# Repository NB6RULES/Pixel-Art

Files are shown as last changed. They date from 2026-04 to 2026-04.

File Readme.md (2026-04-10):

# Pixel-Art

A CoreXY bead-placement machine for creating physical monochrome pixel art on perforated acrylic sheets.

## 3D Model Preview

[View 3D Model on Sketchfab](https://sketchfab.com/3d-models/pixel-art-first-draft-e8df2f01db034dc6a11d05934eb7d457)

## Overview

Pixel-Art is an open-source CNC machine that automatically places beads into a grid of holes on an acrylic sheet, producing physical pixel art from digital images. The machine uses a CoreXY motion system for fast, precise XY movement and a bead dropper mechanism as the end effector.

## Specifications

| Parameter | Value |
|---|---|
| Build Area | 400 × 400 mm |
| Resolution | 2–10 mm per pixel (configurable) |
| Color Mode | Monochrome (black, white, grey beads) |
| Motion System | CoreXY |
| Controller | ESP32 + GRBL |
| Frame | 2020 aluminum extrusion |
| Motors | NEMA17 steppers |
| Belt | GT2 timing belt |

## Roles 

MACHINE GANTERY -- NADEC
END EFFECTOR --- KEVIN
ELECTRONICS -- MERIN
FIRMWARE ---  ARCHITHA
INTERFACE --- KURIAN
DOCUMENTION --- MERIN
FABRICATION AND INTERGRATION --- KURIAN
PRESENTAION & VIDEO (1 MIN) --- ARCHITHA

## TIMELINE

APRIL 09 --  INITAL DISCUSSION AND TEAM ALLOCATION
APRIL 10 --  SKETCH THE DESIGN, MACHINE GANTERY DESIGN AND INTERFACE DESIGN (GET THE GCOD FOR MACHINE)
APRIL 11 --  DESIGN AND FIX THE END EFFECTOR WORKING STRUCTER 
APRIL 12 --  END EFFECTOR DESIGN ( GET THE PROPER MEASURMENT FOR THE BEADS AND BASED ON THAT WE NEEDED TO WORK, **DO IT PARAMETRIC** ), ELECTROCNIC DESIGN 
APRIL 13 --  CHECK THE GCODES WORKING GANTERY MOVEMENT, FIRMWARE 
APRIL 14 --
APRIL 15 -- FABRICATION AND INTERGRATION
APRIL 16 -- 
APRIL 17 --
APRIL 18 --
APRIL 19 --
APRIL (20 - 21) -- VIDEO EDITIONG &  PRESENTAION

## How It Works

1. **Image Input** — A monochrome image is converted to G-code with pixel coordinates mapped to hole positions
2. **Bead Loading** — Beads are loaded into the dropper mechanism (sorted by color)
3. **Placement** — The CoreXY gantry moves to each hole position and the dropper releases a bead
4. **Result** — Completed pixel art on the acrylic sheet

## Bill of Materials

### Frame & Motion

- 2020 V-slot aluminum extrusion
- GT2 timing belt + pulleys (16T/20T)
- NEMA17 stepper motors (×2 for XY)
- Linear rails / V-slot wheels
- 625 bearings for idlers

### Electronics

- ESP32 development board
- DRV8825 / TMC2209 stepper drivers
- 12V/24V power supply
- Limit switches (×3)

### End Effector

- Bead dropper mechanism (servo/solenoid actuated)
- Bead hopper/feeder

### Substrate

- Perforated acrylic sheet (hole spacing matches resolution)
- Beads (2–10 mm diameter, black/white/grey)

## Repository Structure

```
Pixel-Art/
├── Core-XY Movement - Nadec/
│   ├── Solidworks Files/      # Editable CAD files
│   ├── STL AND STEP FILES/    # Export files for fabrication
│   └── initial files/         # Reference designs
├── Documentation/
│   └── Documentation.md
└── README.md
```

## Build Status

- [x] CoreXY gantry design (first draft)
- [ ] End effector dropper mechanism
- [ ] Electronics integration
- [ ] Firmware (ESP32-GRBL)
- [ ] Image-to-Gcode converter
- [ ] Assembly documentation

---

## Git Workflow

### First Time Setup (Clone the Repo)

```bash
git clone https://github.com/NB6RULES/Pixel-Art.git
cd Pixel-Art
git lfs install
git lfs pull
```

> **Note:** This repo uses Git LFS for large STL/STEP files. Run `git lfs install` once on your machine.

### Daily Workflow

#### 1. Always Pull Before You Start Working

```bash
git pull
```

This syncs your local copy with the latest changes from GitHub.

#### 2. Check What's Changed

```bash
git status
```

Shows modified, staged, and untracked files.

#### 3. Stage Your Changes

```bash
# Add specific file
git add filename.SLDPRT

# Add all changes
git add .
```

#### 4. Commit Your Changes

```bash
git commit -m "Brief description of what you changed"
```

Write clear commit messages — future you will thank present you.

#### 5. Pull Again Before Pushing

```bash
git pull
```

**Always pull before push** to avoid merge conflicts, especially when collaborating.

#### 6. Push to GitHub

```bash
git push
```

### Quick Reference

| Command | What it does |
|---|---|
| `git clone <url>` | Download repo for the first time |
| `git pull` | Get latest changes from GitHub |
| `git status` | See what files changed |
| `git add .` | Stage all changes |
| `git commit -m "msg"` | Save changes locally with a message |
| `git push` | Upload commits to GitHub |
| `git log --oneline` | View commit history |

### Golden Rule

```
PULL → WORK → ADD → COMMIT → PULL → PUSH
```

---

## Getting Started

### Prerequisites

- SolidWorks (or use STEP files for other CAD software)
- 3D printer for custom brackets
- Basic CNC/electronics assembly experience

### Assembly

*Documentation in progress*

## Dependencies & Key Libraries

### [GRBL](https://github.com/grbl/grbl)
The original open-source, high-performance G-code motion controller written in optimized C. GRBL is the foundation of the motion control strategy used in this project — it handles real-time step generation, acceleration planning, and G-code parsing. We reference it as the upstream standard that our ESP32 port is based on.

### [Grbl_ESP32 (bdring)](https://github.com/bdring/grbl_esp32)
A port of GRBL adapted specifically for the ESP32 microcontroller. We chose this because the ESP32 offers Wi-Fi connectivity, more GPIO pins, and faster processing than the original Arduino Uno target. This firmware runs directly on our controller board and interprets G-code sent from the image processing pipeline.

### [NeoPI_Wireless (saheenpalayi)](https://github.com/saheenpalayi/NeoPI_Wireless)
A wireless interface layer for sending G-code over Wi-Fi to an ESP32-based CNC controller. We use this (or draw from its approach) to enable cable-free communication between the host computer and the machine — the image-to-G-code output is streamed wirelessly to the ESP32 rather than requiring a USB connection.

---

## Firmware

This project uses [Grbl_Esp32](https://github.com/bdring/Grbl_Esp32) for motion control. Configuration files and pin mappings will be added once electronics design is finalized.

## Software Pipeline

```
Image → Dithering/Thresholding → Grid Mapping → G-code → ESP32-GRBL → Machine
```

A Python script for image processing and G-code generation is planned.

---

## License

*TBD*

---

## Authors

**Nadec Biju**   - COREXY
- GitHub: [@NB6RULES](https://github.com/NB6RULES)

**Architha B K**  
- GitHub: [@architabk618-hue](https://github.com/architabk618-hue)

**Kurian**   - INTERFACE 
- GitHub: [@Kuriyaappi](https://github.com/Kuriyaappi)

**Kevin J Jijo**  - END E
- GitHub: [@mrkubby](https://github.com/mrkubby)

**Merin Menamparambil**  
- GitHub: [@merinmenamparambil](https://github.com/merinmenamparambil)

## CoreXY References

### [CoreXY.com](https://corexy.com/)
The original reference site documenting the CoreXY motion system concept, belt routing geometry, and kinematics. Used as the primary reference for understanding how the two-motor H-bot style drive works and how to correctly route belts to achieve true CoreXY motion without shear forces.

### [Jubilee (Machine Agency)](https://github.com/machineagency/jubilee)
An open-source CoreXY toolchanging machine designed for research and fabrication. Referenced for its well-engineered CoreXY gantry design, use of 2020 extrusion framing, and modular tool head approach — directly relevant to how we've structured our own gantry and end effector mounting.

---

## Acknowledgments

- Inspired by bead art and CNC plotters
- McMaster-Carr for hardware CAD models

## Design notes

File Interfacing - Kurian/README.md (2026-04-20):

# Pixel Bead Placer — CoreXY

A browser-based pixel art editor that streams G-code over USB serial to a CoreXY machine running grbl_esp32, which physically places beads on a configurable bed one at a time.

---

## Table of Contents

1. [Project Purpose](#1-project-purpose)
2. [System Architecture](#2-system-architecture)
3. [Interface Layout](#3-interface-layout)
4. [Left Sidebar — Settings & Tools](#4-left-sidebar--settings--tools)
5. [Canvas Area — Preview](#5-canvas-area--preview)
6. [Right Panel — Machine Control](#6-right-panel--machine-control)
7. [Pre-run Checklist Flow](#7-pre-run-checklist-flow)
8. [USB Serial Communication Protocol](#8-usb-serial-communication-protocol)
9. [GRBL Command Reference](#9-grbl-command-reference)
10. [G-code Program Structure](#10-g-code-program-structure)
11. [Bead Feeder Control](#11-bead-feeder-control)
12. [Coordinate System](#12-coordinate-system)
13. [Grid & Spacing Model](#13-grid--spacing-model)
14. [Image Import](#14-image-import)
15. [SVG Export](#15-svg-export)
16. [Firmware Requirements (ESP32 / grbl_esp32)](#16-firmware-requirements-esp32--grbl_esp32)
17. [Hardware Summary](#17-hardware-summary)
18. [File Structure](#18-file-structure)
19. [Settings Reference](#19-settings-reference)
20. [Changelog](#20-changelog)

---

## 1. Project Purpose

The operator designs a black-and-white pixel image in a browser. The browser app converts it to a grid of bead positions, then streams G-code commands one-by-one over USB serial to a CoreXY robot. The robot moves its end-effector to each position and drops a bead (black or white) using motorised feeders, assembling the physical pixel art on a flat tray.

---

## 2. System Architecture

```
┌─────────────────────────────────────────────────────────┐
│                   Browser (Chrome / Edge)                │
│                                                         │
│  Left sidebar   │   Canvas preview   │  Machine panel   │
│  (settings)     │   (grid, rulers)   │  (serial ctrl)   │
│                                                         │
│         Web Serial API (USB CDC, 115200 baud)           │
└──────────────────────────┬──────────────────────────────┘
                           │ USB
                           ▼
              ┌────────────────────────┐
              │   ESP32 dev board      │
              │   grbl_esp32 firmware  │
              │   (GRBL 1.1 protocol)  │
              └────────────┬───────────┘
                           │ Step/Dir signals
                           ▼
              ┌────────────────────────┐
              │   CoreXY motion system │
              │   + 2 bead feeders     │
              │   + limit switches     │
              └────────────────────────┘
```

**Communication path:** Browser → Web Serial API → USB CDC → ESP32 UART0 → grbl_esp32

**Data format:** Plain ASCII text, newline-terminated (`\n`). No binary framing, no checksum.

---

## 3. Interface Layout

The app is a single-page HTML application with three columns inside a full-viewport layout:

```
┌──────────────────────────────────────────────────────────────────────┐
│  HEADER: title + "Generate & Download GCode" button                   │
├──────────────┬───────────────────────────────┬───────────────────────┤
│  LEFT PANEL  │        CANVAS AREA            │    RIGHT PANEL        │
│  224 px      │        flex: 1 (scrollable)   │    262 px             │
│              │                               │                       │
│  • Bed/Bead  │  Y ruler │ Grid preview       │  • Serial connect     │
│    Setup     │  (left)  │ (bead circles)     │  • Pre-run checklist  │
│              │          │                    │  • Machine state      │
│  • Bead      │          │ X ruler (bottom)   │  • Jog controls       │
│    Count     │                               │  • Print job          │
│              │                               │  • Terminal           │
│  • Colors    │                               │                       │
│              │                               │                       │
│  • Tools     │                               │                       │
│              │                               │                       │
│  • Machine   │                               │                       │
│    Settings  │                               │                       │
│              │                               │                       │
│  • Actions   │                               │                       │
└──────────────┴───────────────────────────────┴───────────────────────┘
```

---

## 4. Left Sidebar — Settings & Tools

### 4.1 Bed & Bead Setup

Inputs that define the physical machine and the design grid. All are numbers in mm.

| Field | HTML ID | Default | Description |
|---|---|---|---|
| Bed width | `#bed-w` | 400 | Machine bed width in mm |
| Bed height | `#bed-h` | 400 | Machine bed height in mm |
| Bead size | `#bead-diameter` | 6 | Physical bead diameter in mm |
| Gap | `#bead-gap` | 1 | Edge-to-edge clearance between beads in mm |
| Spacing (read-only) | `#spacing-val` | 7 | Auto-computed: diameter + gap |

Click **Apply Grid** to commit these values. The canvas will render and all design tools unlock. If a design already exists and values change, the user is asked to confirm clearing it.

### 4.2 Bead Count (shown after Apply Grid)

Live stats displayed in `#grid-info`:
- Grid: cols × rows
- Total beads
- Black bead count
- White bead count

A warning banner appears if total > 40,000 beads (large G-code file).

### 4.3 Colors

Three `<input type="color">` pickers, all live (no Apply needed):

| Picker | HTML ID | Default | Controls |
|---|---|---|---|
| Black bead | `#color-black` | `#1a1a1a` | Fill color of black bead circles on canvas |
| White bead | `#color-white` | `#f0f0f0` | Fill color of white bead circles on canvas |
| Space | `#color-space` | `#999999` | Background between beads |

### 4.4 Tools (locked until Apply Grid)

- **Pen** (`data-tool="pen"`) — click/drag to place black beads
- **Eraser** (`data-tool="eraser"`) — click/drag to place white beads (remove black)
- **Show Path** (`#btn-path`) — toggles the snake path overlay on the canvas

### 4.5 Machine Settings

These values feed directly into G-code generation and the machine panel:

| Field | HTML ID | Default | Description |
|---|---|---|---|
| Origin X | `#origin-x` | 0 | X offset added to all G-code positions |
| Origin Y | `#origin-y` | 0 | Y offset added to all G-code positions |
| Move speed | `#move-speed` | 800 | Feed rate for positioning moves in mm/min |
| Dwell time | `#dwell-time` | 300 | `G4 P` value in ms; wait after each bead drop |
| Black bead | `#black-bead-side` | Left | Which side of the dropper dispenses black beads |
| White bead | `#white-bead-side` | Right | Which side of the dropper dispenses white beads |

### 4.6 Actions (locked until Apply Grid)

- **Import Image** (`#btn-import`) — opens a file picker; image is luminance-thresholded to black/white and mapped to the grid
- **Download SVG** (`#btn-svg`) — saves a physically accurate SVG of the current design
- **Clear All** (`#btn-clear`) — resets all beads to white (after user confirm)

The header button **Generate & Download GCode** (`#btn-gcode`) saves the current design as a `.gcode` file.

---

## 5. Canvas Area — Preview

### 5.1 Coordinate System

The canvas uses a **Y-up coordinate system** matching standard machine/CAD conventions:

- **(0, 0) is at the bottom-left** corner of the bed
- **X increases to the right**
- **Y increases upward**
- Row 0 in the grid array = bottom-most row on screen = smallest Y in G-code
- Row N-1 in the grid array = top-most row on screen = largest Y in G-code

### 5.2 Canvas Layout

```
Canvas pixel layout:

 y=0 ──────────────────────────────────────
      │  Y ruler  │     Grid area          │
      │  (44 px)  │  (cols × cellPx wide)  │
      │           │                        │
      │  Y=max    │  row N-1 (top)         │
      │  at top   │                        │
      │  Y=0      │  row 0 (bottom)        │
      │  at btm   │                        │
 y=rows*cellPx ──┼────────────────────────┤
      │  corner   │     X ruler            │
      │  "mm"     │  (canvas width wide)   │
 y=canvas.height ─────────────────────────
      │← RULER_PX→│←── cols × cellPx ─────│
```

- `RULER_PX = 44` px — width of Y ruler strip (also height of X ruler strip)
- `cellPx = clamp(floor(680 / cols), 5, 40)` — pixels per bead cell

### 5.3 Rulers

- **Y ruler** (left, 44 px wide): tick marks at every `rulerLabelStep()` rows; labels show Y in mm; small ▶/◀ arrows show snake-path travel direction per row
- **X ruler** (bottom, 44 px tall): tick marks at every `rulerLabelStep()` cols; labels show X in mm
- **Corner square** at bottom-left: labelled "mm"
- Tick density adapts to zoom level — minimum 45 px between major tick labels

### 5.4 Grid Rendering

Each bead is a filled circle:

```
radiusPx = (beadDiameterMm / beadSpacingMm) × cellPx × 0.5
```

Bead at grid position (col, row):
```
canvas_x = RULER_PX + col × cellPx + cellPx / 2
canvas_y = (rows - 1 - row) × cellPx + cellPx / 2
```

Background (space between beads) = `colorSpace`; black bead = `colorBlack`; white bead = `colorWhite`.

### 5.5 Snake Path Overlay

When **Show Path** is active, a semi-transparent red line traces the full travel sequence:
- Even rows (0, 2, 4…): left → right
- Odd rows (1, 3, 5…): right → left
- Arrowheads at the start of every labelled row

---

## 6. Right Panel — Machine Control

All machine interaction is in the right panel (262 px wide). It is always visible regardless of grid state.

### 6.1 Serial Connection

- **Connect USB** button (`#btn-serial-connect`) — calls `navigator.serial.requestPort()` and opens at 115200 baud
- Status indicator: green dot = connected, dark dot = disconnected
- On connect: all machine buttons enable; status is polled after 1.2 s
- On disconnect: all buttons disable; running job is aborted; cmdQueue is flushed

### 6.2 Pre-run Checklist

Seven items. Each has a state: `pending` (○), `busy` (…), `done` (✓). Items 2–6 have action buttons that become enabled once connected.

| # | ID | Label | Action | How it completes |
|---|---|---|---|---|
| 1 | `#chk-connect` | Connect to machine | (automatic) | Ticks on USB connect |
| 2 | `#chk-home` | Home axes (limit switches) | Run $H | Sends `$H`, waits for `ok` |
| 3 | `#chk-origin` | Move to origin X/Y | Go | Sends `G21 G90 G0 X{ox} Y{oy}`, waits for `ok` |
| 4 | `#chk-testx` | Test X axis movement | Test | Jogs X+ then X−, user confirms |
| 5 | `#chk-testy` | Test Y axis movement | Test | Jogs Y+ then Y−, user confirms |
| 6 | `#chk-testbead` | Test bead drop | Test | Moves to slot 1 → drops black bead → moves to slot 2 → drops white bead; user confirms each |
| 7 | `#chk-ready` | Ready to print | (automatic) | Ticks when items 1–6 all done |

When **Run** is clicked and the checklist is not fully complete, the user is shown a warning and can proceed anyway.

### 6.3 Machine State

Polled by sending `?` to GRBL. The response (`<...>` status report) is parsed silently (not shown in terminal) and updates:

| Display | ID | Source |
|---|---|---|
| Status | `#mc-status` | First field of status report (e.g. `Idle`, `Run`, `Alarm`) |
| X position | `#mc-pos-x` | `WPos:x,...` parsed from status report |
| Y position | `#mc-pos-y` | `WPos:x,y,...` parsed from status report |

The `?` button (`#btn-poll`) manually triggers a poll.

### 6.4 Jog Controls

3×3 directional pad. All jog commands use GRBL jogging (`$J=`) in relative mode:

```
$J=G91 G21 X{±step} F{feed}
$J=G91 G21 Y{±step} F{feed}
```

- **Step size** (`#jog-step`): 1 / 5 / 10 / 50 mm
- **Feed rate** (`#jog-feed`): slow=1000, med=3000, fast=6000 mm/min
- **⌂ button** (`#jog-center`): sends `G0 X{originX} Y{originY} F3000` — returns to user-defined origin
- All jog buttons disabled during a running or paused job

### 6.5 Print Job

- **▶ Run** (`#btn-run-gcode`) — builds G-code from current grid state via `buildGcodeLines()`, then streams lines one-by-one
- **⏸ Pause** — sets `jobPaused = true`; current line finishes; no new lines sent; button changes to **▶ Resume**
- **■ Stop** — sets job state to stopped; sends `!` (feed hold) then `\x18` (soft reset) 250 ms later
- Progress bar and `Line N / total (N%)` counter update after each line sent
- Run button enabled when: serial connected AND grid is ready (`gridReady = true`)

### 6.6 Terminal

- Colour-coded log of all serial traffic:
  - `← ` green — data received from machine (RX)
  - `→ ` blue — data sent to machine (TX)
  - `# ` grey — system messages from the browser app
  - `✗ ` red — errors
- GRBL status reports (`<...>`) are parsed silently and do **not** appear in the terminal (to avoid flooding during a job)
- Manual command input (`#serial-cmd`) — type any GRBL command and press Enter or Send
- **Clear** button wipes the terminal log
- Capped at 600 lines (oldest lines removed automatically)

---

## 7. Pre-run Checklist Flow

The expected sequence before every print run:

```
Step 1: Connect USB
  → User clicks "Connect USB"
  → Browser opens port picker dialog
  → Port opens at 115200 baud
  → App waits 1.2 s, sends ?
  → chk-connect ticks ✓

Step 2: Home axes
  → User clicks "Run $H"
  → App sends:  $H\n
  → GRBL runs homing cycle (moves to limit switches)
  → GRBL replies: ok
  → chk-home ticks ✓
  → App sends ? to refresh position display
  (If ALARM state, user must send $X in terminal first)

Step 3: Move to origin
  → User clicks "Go"
  → App sends:  G21\n   (mm mode)
                G90\n   (absolute)
                G0 X{originX} Y{originY} F3000\n
  → GRBL replies: ok, ok, ok
  → chk-origin ticks ✓
  → App sends ? to refresh position display

Step 4: Test X axis
  → User clicks "Test"
  → App sends:  $J=G91 G21 X{step} F{feed}\n
  → GRBL replies: ok
  → App sends:  $J=G91 G21 X{-step} F{feed}\n
  → GRBL replies: ok
  → Browser shows confirm dialog: "Did the machine move correctly in X?"
  → User clicks OK → chk-testx ticks ✓
  → User clicks Cancel → item stays pending, can retry

Step 5: Test Y axis
  → Same as step 4 but Y direction

Step 6: Test bead drop
  → User clicks "Test"
  → App sends:  G1 X{slot1X} Y{slot1Y} F{speed}\n   (move to first bead slot)
  → GRBL replies: ok
  → App sends:  G4 P0\n                               (full stop)
  → App sends:  M3 S{BLACK}\n                         (drop black bead)
  → App sends:  G4 P{dwellMs}\n                       (dwell)
  → App sends:  M3 S60\n                              (rest)
  → Browser shows confirm: "Did a BLACK bead drop?" → OK to continue
  → App sends:  G1 X{slot2X} Y{slot2Y} F{speed}\n   (move to next slot)
  → Same sequence for white bead
  → Both confirmed → chk-testbead ticks ✓

Step 7: Ready to print
  → Auto-ticks when all 6 above are ✓

Step 8: Run
  → User clicks ▶ Run
  → App builds G-code from current grid
  → Streams line-by-line (see §8.3)
```

---

## 8. USB Serial Communication Protocol

### 8.1 Physical Layer

| Parameter | Value |
|---|---|
| Interface | USB CDC (virtual COM port) |
| Baud rate | 115200 |
| Data bits | 8 |
| Stop bits | 1 |
| Parity | None |
| Flow control | None (software flow control via GRBL `ok` responses) |
| Browser API | Web Serial API (Chrome ≥ 89, Edge ≥ 89) |

### 8.2 Message Format

All messages are plain ASCII terminated by `\n` (LF, `0x0A`). GRBL may send `\r\n` — the app strips `\r` before processing.

**Browser → Machine (TX):**  each command is a single line followed by `\n`

**Machine → Browser (RX):**  GRBL sends one response per command received

### 8.3 Flow Control — ok Gating

The app uses strict single-command flow control:

```
Browser sends line 1 ──→ Machine
                     ←── ok
Browser sends line 2 ──→ Machine
                     ←── ok
...
```

Only one line is in flight at any time. The next line is sent only after `ok` is received for the previous one. This prevents GRBL's 128-byte RX buffer from overflowing.

**Implementation:**
- `sendCmd(cmd)` — returns a Promise that resolves on `ok`, rejects on `error:N` or `ALARM:N`
- `sendRaw(cmd)` — fire-and-forget (used for `?`, `!`, `\x18` which don't follow the ok protocol)
- During a job, incoming `ok` triggers `sendNextJobLine()`
- During interactive use (checklist, jog, terminal), `ok` resolves the top entry in `cmdQueue[]`

### 8.4 Response Types

| Response | When sent | App behaviour |
|---|---|---|
| `ok` | After any valid command executes | Advances job queue or resolves cmdQueue promise |
| `error:N` | Invalid command or parameter | Logs to terminal; pauses job if running |
| `ALARM:N` | Machine alarm (limit hit, homing fail, etc.) | Logs to terminal; stops job; cmdQueue rejected |
| `<State\|WPos:x,y,z\|...>` | Response to `?` status request | Parsed silently; updates status display |
| `[MSG:...]` | Informational messages (e.g. homing) | Shown in terminal |
| `Grbl N.N ...` | Welcome message on connect/reset | Shown in terminal |
| `$` settings replies | Response to `$$` | Shown in terminal |

### 8.5 Special Real-time Commands

These are single-byte commands sent without `\n`. They are processed by GRBL immediately, bypassing the command buffer:

| Byte | Command | Effect |
|---|---|---|
| `?` | Status request | GRBL sends `<State\|WPos:x,y,z\|...>` immediately |
| `!` | Feed hold | Machine decelerates to stop; state → `Hold` |
| `~` | Cycle start / resume | Resumes from Hold |
| `\x18` (Ctrl-X) | Soft reset | Resets GRBL; clears alarms; machine state lost |

The Stop button sends `!` then `\x18` after 250 ms.

### 8.6 Status Report Format

GRBL sends a status report in response to `?`:

```
<Idle|WPos:10.500,25.000,0.000|FS:0,0>
<Run|WPos:10.500,25.000,0.000|FS:3000,0>
<Alarm:9|WPos:0.000,0.000,0.000|FS:0,0>
<Hold:0|WPos:10.500,25.000,0.000|FS:0,0>
```

Fields:
- **State**: `Idle`, `Run`, `Hold:0`, `Hold:1`, `Jog`, `Alarm:N`, `Door:N`, `Check`, `Home`, `Sleep`
- **WPos**: Work position X, Y, Z in mm (after applying work coordinate offset)
- **FS**: Feed rate (mm/min), Spindle speed (RPM)

The app parses `WPos` with:
```
/WPos:([-\d.]+),([-\d.]+)/
```

### 8.7 Homing Response Sequence

After `$H` is sent, GRBL typically responds:

```
[MSG:Caution: Unlocked]      ← if previously in ALARM
ok                            ← homing complete; machine now at (0,0,0)
```

Or on failure:
```
ALARM:9                       ← homing failed (limit switch not triggered)
```

If machine is in ALARM before homing, send `$X` first to unlock, then `$H`.

### 8.8 Jog Command Format

```
$J=G91 G21 X10 F3000\n
```

- `$J=` — jog prefix (GRBL 1.1+)
- `G91` — relative positioning for this move
- `G21` — mm units
- `X10` or `Y-5` — axis and distance
- `F3000` — feed rate in mm/min

GRBL responds with `ok` when the jog completes or is cancelled. Sending another `$J` while jogging cancels the current jog and starts the new one.

---

## 9. GRBL Command Reference

All commands used by this application:

| Command | Description | Expected Response |
|---|---|---|
| `?` | Request status report | `<State\|WPos:...>` (no `ok`) |
| `$H` | Run homing cycle | `ok` (after homing completes) |
| `$X` | Clear ALARM state (unlock) | `ok` |
| `$J=G91 G21 X{n} F{f}` | Jog X relative | `ok` |
| `$J=G91 G21 Y{n} F{f}` | Jog Y relative | `ok` |
| `G21` | Set units to mm | `ok` |
| `G90` | Absolute positioning mode | `ok` |
| `G28` | Go to pre-defined home position | `ok` |
| `G1 X{x} Y{y} F{f}` | Controlled linear move to position | `ok` |
| `G4 P0` | Flush planner — ensure machine fully stopped | `ok` |
| `G4 P{ms}` | Dwell for N milliseconds | `ok` (after dwell) |
| `M3 S110` | Servo → Left bead | `ok` |
| `M3 S22` | Servo → Right bead | `ok` |
| `M3 S60` | Servo → Rest (neutral) | `ok` |
| `M30` | End of program | `ok` |
| `!` | Feed hold (real-time, no `\n`) | (machine decelerates) |
| `\x18` | Soft reset (real-time, no `\n`) | `Grbl N.N ...` welcome |

---

## 10. G-code Program Structure

The full G-code program generated by `buildGcodeLines()`:

```gcode
; Pixel Bead Placer — GCode
; Firmware      : grbl_esp32 (GRBL 1.1 compatible)
; Bed size      : 400 x 400 mm
; Bead diameter : 6 mm
; Bead gap      : 1 mm  (edge-to-edge clearance)
; Bead spacing  : 7 mm  (center-to-center = diameter + gap)
; Grid          : 57 x 57  (3,249 beads)
; Black beads   : 1420
; White beads   : 1829
; Origin        : X0 Y0 mm
; Dwell/bead    : 300 ms
; Generated     : 2024-01-15T10:23:00.000Z
;
; Servo control (GPIO 27, 50Hz PWM):
;   M3 S110  →  Left  bead
;   M3 S22   →  Right bead
;   M3 S60   →  Rest (neutral)
;   BLACK bead = left side (M3 S110)
;   WHITE bead = right side (M3 S22)

G21            ← mm units
G90            ← absolute positioning
M3 S60         ← servo to rest before homing
G28            ← home all axes (machine goes to 0,0,0)

; Row 0  (L→R)
G1 X3.50 Y3.50 F800    ← controlled move to slot
G4 P0                  ← full stop before drop
M3 S110                ← drop black bead (left side)
G4 P0.300              ← dwell 300 ms
M3 S60                 ← servo back to rest

G1 X10.50 Y3.50 F800
G4 P0
M3 S22                 ← drop white bead (right side)
G4 P0.300
M3 S60
...

; Row 1  (R→L)
...

G28          ← return to home
M30          ← end of program
```

**Streaming rule:** Comment lines (starting with `;`) and blank lines are skipped when streaming. Only executable lines are sent to the machine. Each executable line waits for `ok` before the next is sent.

---

## 11. Bead Dropper Control

A single servo on GPIO 27 dispenses beads by rotating left or right from a neutral rest position. All control is via `M3 S{value}` — no M4 or M5 used.

### Calibrated S values

| Command | Action |
|---|---|
| `M3 S110` | Servo → Left position |
| `M3 S22` | Servo → Right position |
| `M3 S60` | Servo → Rest (neutral) |

### Bead side assignment

The user configures which physical side holds each bead colour in the Machine Settings panel. The generated S values adjust accordingly:

| User setting | Black bead command | White bead command |
|---|---|---|
| Black=Left, White=Right | `M3 S110` | `M3 S22` |
| Black=Right, White=Left | `M3 S22` | `M3 S110` |

### Per-bead drop sequence

Every bead — regardless of colour — follows this exact sequence:

```
G1 X{x} Y{y} F{speed}   ← controlled move to bead slot
G4 P0                    ← flush planner; full stop
M3 S{BLACK or WHITE}     ← rotate servo to drop bead
G4 P{dwell}              ← wait for bead to fall
M3 S60                   ← return servo to rest
```

`G4 P0` before the servo command guarantees the machine has fully decelerated and stopped before any bead is released, preventing mis-drops at speed.

**Startup:** `M3 S60` is sent before `G28` so the servo is always in the rest position before homing begins.

**Dwell (`G4 P{ms}`):** Default 300 ms, configurable 10–9999 ms.

**Move speed:** Default 800 mm/min (`G1 F800`), configurable 100–5000 mm/min.

---

## 12. Coordinate System

### 12.1 Machine Coordinates

- Machine home (after `$H`): X=0, Y=0
- X increases in one direction across the bed
- Y increases in the other direction across the bed (perpendicular to X in a CoreXY frame, but motion is coupled)
- Z is not used (the end-effector height is fixed)

### 12.2 G-code Bead Coordinates

For bead at grid position (col, row):

```
X_mm = originX + col × beadSpacingMm + beadSpacingMm / 2
Y_mm = originY + row × beadSpacingMm + beadSpacingMm / 2
```

- `originX`, `originY` — user-defined offset from machine home (default 0, 0)
- `beadSpacingMm` = bead diameter + gap
- `+ beadSpacingMm / 2` — centres the end-effector on the bead position

Row 0 = lowest Y value = front of bed = starts bottom-left in preview.

### 12.3 Snake Path

```
Row 0:  col 0 → col 1 → ... → col N-1    (left to right,  even rows)
Row 1:  col N-1 → ... → col 1 → col 0   (right to left,  odd rows)
Row 2:  col 0 → col 1 → ... → col N-1   (left to right,  even rows)
...
```

This minimises total travel distance by avoiding retracing the X axis at the end of each row.

### 12.4 Preview vs Machine Coordinates

The canvas preview matches the machine coordinate system exactly:
- (0,0) = bottom-left of canvas grid = machine origin (0+offset, 0+offset)
- Y increases upward in the preview (flipped from screen Y)
- X ruler at bottom, Y ruler at left

---

## 13. Grid & Spacing Model

```
beadSpacingMm = beadDiameterMm + beadGapMm

cols = floor(bedWidthMm  / beadSpacingMm)
rows = floor(bedHeightMm / beadSpacingMm)
```

Example: 400×400 mm bed, 6 mm bead, 1 mm gap:
- spacing = 7 mm
- cols = floor(400/7) = 57
- rows = floor(400/7) = 57
- total = 3,249 beads

The gap is edge-to-edge clearance — the physical space between adjacent bead edges. Center-to-center pitch equals diameter + gap.

Canvas cell size: `cellPx = clamp(floor(680 / cols), 5, 40)`

Circle radius on canvas: `radiusPx = (beadDiameterMm / beadSpacingMm) × cellPx × 0.5`

---

## 14. Image Import

1. User selects any image file (JPEG, PNG, GIF, WebP, etc.)
2. Image is drawn to an offscreen canvas scaled to `cols × rows`
3. Each pixel's luminance is computed:
   ```
   luma = 0.299 × R + 0.587 × G + 0.114 × B
   ```
4. `luma < 128` → black bead (`grid[r][c] = 1`)
5. `luma ≥ 128` → white bead (`grid[r][c] = 0`)
6. The result replaces the current design; stats and canvas update immediately

The offscreen canvas uses `fillStyle = '#ffffff'` before drawing to ensure transparent pixels map to white.

---

## 15. SVG Export — Laser Cut Template

The **Download SVG** button generates a laser-cutting template for the physical base plate.

### Purpose

The SVG is used to laser-cut the bead holder plate — a flat sheet with a hole at every bead position. The operator places this plate on the machine bed; the CoreXY end-effector drops beads through the holes into the tray below.

### Format

- **No fills** — outlines only (`fill="none"`)
- **Stroke colour: red** (`stroke="red"`) — standard colour used by laser cutter software to identify cut paths
- **Stroke width: 0.1 mm** (`stroke-width="0.1"`) — hairline cut line
- **Bed border** — one rectangle at the outer edge of the plate
- **Bead holes** — one circle per bead position, all identical regardless of black/white color in the design
- **File name:** `bead_plate_lasercut.svg`

### Example output

```xml
<svg xmlns="http://www.w3.org/2000/svg"
     width="400mm" height="400mm"
     viewBox="0 0 400 400">
  <g fill="none" stroke="red" stroke-width="0.1">
    <rect x="0" y="0" width="400" height="400"/>  <!-- bed border -->
    <circle cx="3.500" cy="3.500" r="3"/>          <!-- bead hole -->
    <circle cx="10.500" cy="3.500" r="3"/>
    ...
  </g>
</svg>
```

### Geometry

- `cx = col × beadSpacingMm + beadSpacingMm / 2`
- `cy = row × beadSpacingMm + beadSpacingMm / 2`
- `r  = beadDiameterMm / 2`
- All values in mm; SVG `width`/`height` set in mm so scale is 1:1 physical

Note: SVG Y-axis is top-down (row 0 at top). This does not affect the laser cut result since the plate is physically symmetric.

---

## 16. Firmware Requirements (ESP32 / grbl_esp32)

Any firmware flashed to the ESP32 must satisfy these requirements for the browser app to work correctly.

### 16.1 Protocol

- **GRBL 1.1 compatible** — the app assumes standard GRBL 1.1 command and response format
- **USB CDC serial** at **115200 baud**, 8N1
- Send a welcome string on boot: `Grbl N.N ['$' for help]` — this lets the app detect connection
- Respond `ok` (lowercase, alone on a line) after every successfully received and queued command
- Respond `error:N` for invalid commands (N = GRBL error code)
- Respond `ALARM:N` for alarm conditions

### 16.2 Commands the Firmware Must Handle

| Command | Required behaviour |
|---|---|
| `?` | Immediately respond with `<State\|WPos:x,y,z\|FS:feed,spindle>` without consuming an `ok` slot |
| `$H` | Run homing cycle using limit switches; respond `ok` when complete |
| `$X` | Clear alarm state; respond `ok` |
| `G21` | Set internal units to mm; respond `ok` |
| `G90` | Set absolute positioning mode; respond `ok` |
| `G28` | Move to stored home position (or machine zero); respond `ok` |
| `G0 X{x} Y{y} F{f}` | Rapid linear move to absolute position; respond `ok` when move completes |
| `G4 P{ms}` | Dwell for specified milliseconds; respond `ok` after dwell |
| `M3 S110` | Servo to left position; respond `ok` |
| `M3 S22` | Servo to right position; respond `ok` |
| `M3 S60` | Servo to rest (neutral); respond `ok` |
| `M30` | End of program; respond `ok` |
| `$J=G91 G21 X{n} F{f}` | Execute relative jog move; respond `ok` |
| `!` | Feed hold (real-time byte, no `ok` sent) |
| `\x18` | Soft reset (real-time byte; re-send welcome string) |

### 16.3 Spindle → Servo Mapping

The ESP32 firmware maps GRBL spindle S-values to PWM pulse widths on GPIO 27 (50 Hz BESC output):

```
M3 S110  →  Left  position  (drops left bead)
M3 S22   →  Right position  (drops right bead)
M3 S60   →  Rest  position  (neutral — no bead dropped)
```

Firmware type: `SPINDLE_TYPE = BESC`, output pin: `GPIO_NUM_27`. The S-value maps linearly to pulse width within the configured min/max range.

### 16.4 Homing

- Limit switches must be connected to the ESP32 inputs configured in grbl_esp32 settings
- `$H` triggers the homing cycle: machine moves toward limit switches at homing speed, backs off, and sets machine position to (0, 0, 0)
- After homing, `WPos` in status reports should read `0.000, 0.000, 0.000`
- Homing direction and speed are configured via GRBL `$` settings (e.g. `$23`, `$24`, `$25`)

### 16.5 Position Reporting

The `?` status response must include work position (`WPos`):
```
<Idle|WPos:10.500,25.000,0.000|FS:3000,100>
```

The app parses only X and Y from `WPos`. Z is ignored. `MPos` (machine position) can also be used if WPos is not available — update the regex in `parseGrblStatus()` accordingly.

### 16.6 GRBL Settings (recommended starting values)

Configure via `$$` command in the GRBL terminal:

| Setting | Parameter | Recommended |
|---|---|---|
| `$0` | Step pulse time (µs) | 10 |
| `$1` | Step idle delay (ms) | 25 |
| `$2` | Step port invert mask | depends on wiring |
| `$3` | Direction port invert | depends on wiring |
| `$4` | Step enable invert | 0 |
| `$20` | Soft limits enable | 1 |
| `$21` | Hard limits enable | 1 |
| `$22` | Homing cycle enable | 1 |
| `$23` | Homing direction invert | depends on wiring |
| `$24` | Homing feed rate (mm/min) | 25 |
| `$25` | Homing seek rate (mm/min) | 500 |
| `$27` | Homing pull-off (mm) | 1 |
| `$100` | X steps/mm | calibrate to hardware |
| `$101` | Y steps/mm | calibrate to hardware |
| `$110` | X max rate (mm/min) | e.g. 5000 |
| `$111` | Y max rate (mm/min) | e.g. 5000 |
| `$120` | X acceleration (mm/s²) | e.g. 200 |
| `$121` | Y acceleration (mm/s²) | e.g. 200 |
| `$130` | X max travel (mm) | = bed width |
| `$131` | Y max travel (mm) | = bed height |

---

## 17. Hardware Summary

| Component | Specification |
|---|---|
| Controller | ESP32 (any variant with USB CDC or USB-UART bridge) |
| Firmware | grbl_esp32 (GRBL 1.1 compatible) |
| Motion | CoreXY kinematics |
| Motors | 2× stepper (X/Y combined for CoreXY) |
| Drivers | Any GRBL-compatible stepper driver (e.g. DRV8825, TMC2208) |
| Limit switches | Min X, Min Y (or Max, depending on homing direction) |
| Bead dropper | 1× servo on GPIO 27 (50 Hz PWM) — left/right/rest positions |
| - Left position | `M3 S110` |
| - Right position | `M3 S22` |
| - Rest (neutral) | `M3 S60` |
| Bed | Flat tray, configurable size (default 400×400 mm) |
| Bead size | 6 mm diameter (default), 1 mm gap, 7 mm pitch |
| Host | PC/Mac/Linux running Chrome or Edge (Web Serial API) |

---

## 18. File Structure

```
pixel_art/
├── index.html    — Full page structure: left sidebar, canvas, right machine panel
├── style.css     — All styles (dark theme, sidebar, canvas, machine panel, terminal)
├── script.js     — All application logic:
│                   • Grid state and rendering
│                   • Ruler and snake path drawing
│                   • Mouse drawing (pen/eraser)
│                   • Image import and SVG export
│                   • buildGcodeLines() — G-code builder (shared)
│                   • G-code download
│                   • Web Serial API connect/disconnect/read loop
│                   • GRBL protocol handling (ok/error/alarm/status)
│                   • Checklist step handlers
│                   • Jog controls
│                   • Job streaming (sendNextJobLine, pause, stop)
│                   • Terminal logging
└── README.md     — This file
```

---

## 19. Settings Reference

### Design Settings

| Setting | HTML ID | Default | Min | Max | Step | Unit |
|---|---|---|---|---|---|---|
| Bed width | `#bed-w` | 400 | 10 | 2000 | 10 | mm |
| Bed height | `#bed-h` | 400 | 10 | 2000 | 10 | mm |
| Bead diameter | `#bead-diameter` | 6 | 0.5 | 200 | 0.5 | mm |
| Bead gap | `#bead-gap` | 1 | 0.1 | 50 | 0.1 | mm |
| Spacing | `#spacing-val` | 7 | — | — | — | mm (computed) |

### Machine Settings

| Setting | HTML ID | Default | Min | Max | Step | Unit |
|---|---|---|---|---|---|---|
| Origin X | `#origin-x` | 0 | −9999 | 9999 | 1 | mm |
| Origin Y | `#origin-y` | 0 | −9999 | 9999 | 1 | mm |
| Move speed | `#move-speed` | 800 | 100 | 5000 | 100 | mm/min |
| Dwell time | `#dwell-time` | 300 | 10 | 9999 | 10 | ms |
| Black bead side | `#black-bead-side` | Left | — | — | — | Left / Right |
| White bead side | `#white-bead-side` | Right | — | — | — | Left / Right |

### Jog Settings (machine panel)

| Setting | HTML ID | Options | Default |
|---|---|---|---|
| Step size | `#jog-step` | 1, 5, 10, 50 mm | 10 mm |
| Feed rate | `#jog-feed` | 1000, 3000, 6000 mm/min | 3000 (med) |

---

## 20. Changelog

### v10 — Calibrated servo, configurable bead sides, controlled motion

#### Machine / G-code
- **Calibrated S values** — replaced theoretical values with physically tested positions:
  - `M3 S110` → Left bead
  - `M3 S22`  → Right bead
  - `M3 S60`  → Rest (neutral)
- **Configurable bead sides** — new "Black bead" and "White bead" dropdowns let user assign which physical side holds each colour; GCode S-values update automatically
- **Startup rest** — `M3 S60` now sent before `G28` so servo is always in rest position before homing
- **Controlled moves** — positioning changed from rapid `G0` to feed-rate-controlled `G1`; default 800 mm/min, configurable 100–5000 mm/min
- **Full stop before drop** — `G4 P0` inserted after every move to flush the GRBL planner and guarantee machine is fully stopped before servo fires; eliminates mid-motion mis-drops
- **Bead drop test moves to separate slots** — test now drives to slot 1 (first bead position) for black drop, then to slot 2 (next slot, one spacing away) for white drop; both beads land in their own grid holes

#### UI — Machine Settings
- **Move speed input** — new `#move-speed` field (default 800 mm/min, 100–5000 range) controls feed rate for all positioning moves and bead test moves
- **Black bead side / White bead side** — two select dropdowns (`Left` / `Right`) determine which servo direction maps to each colour

#### Previous v10 additions (from earlier sessions)
- **Servo bead dropper** — end-effector servo on GPIO 27 replaces dual-feeder spindle model; M4/M5 removed
- **Per-bead servo cycle** — `G1 → G4 P0 → M3 S{val} → G4 P{dwell} → M3 S60`
- **G4 dwell fixed** — correctly sends `G4 P0.300` (300 ms) not `G4 P300` (300 s)
- **Skip bead drop test** — "Skip" button in checklist
- **Auto machine state poll** — Idle/Run/Alarm + position every 2 s
- **Time estimation** — est. time shown before job; elapsed/ETA during job
- **Terminal copy button**, MPos parser, split status fix

---

### v9 — SVG export changed to laser-cut template

- **Outlines only** — removed all fills; SVG now has `fill="none"` throughout
- **Red stroke** — all paths use `stroke="red"` (standard laser-cut colour)
- **0.1 mm stroke width** — hairline weight suitable for laser cutter cut paths
- **Bed border added** — outer rectangle at exact bed dimensions marks the plate boundary
- **All holes identical** — every bead position gets a circle regardless of black/white; the SVG is a cutting template, not a colour preview
- **File renamed** — downloads as `bead_plate_lasercut.svg` to clarify its purpose

### v8 — USB Serial machine control panel

- **Web Serial API** — browser connects directly to ESP32 via USB (Chrome/Edge ≥ 89)
- **Right panel** — 262 px panel added to the right of the canvas with all machine controls
- **Pre-run checklist** — 7-step sequential verification process before every print
- **Homing** — `$H` command with `ok`-gated response; ALARM unlock hint shown on failure
- **Origin move** — `G21 G90 G0 X Y` sequence driven by sidebar Origin X/Y values
- **X/Y axis tests** — relative jogs with browser confirm dialog for user verification
- **Bead drop test** — `M3 S100 → G4 P{dwell} → M5` sequence with user confirm
- **Machine state display** — parsed from GRBL `<WPos:...>` status reports
- **Jog pad** — 3×3 directional pad with configurable step and feed; ⌂ goes to origin
- **G-code streaming** — `ok`-gated line-by-line send from `buildGcodeLines()`
- **Pause / Resume / Stop** — pause after current line; stop sends `!` + `\x18`
- **Progress tracking** — bar and `line N / total (N%)` counter
- **Terminal** — colour-coded RX/TX/system/error log; manual send; 600-line cap
- **`buildGcodeLines()`** — refactored shared function used by both download and streamer

### v7 — X ruler moved to bottom

- X ruler relocated to bottom of canvas; both axes now meet at bottom-left corner
- Canvas layout: grid at y=0, X ruler below grid, Y ruler on left; origin corner at bottom-left
- All grid Y pixel coordinates updated (no top offset); `cellFromEvent()` updated accordingly

### v6 — Y-up coordinate system (origin at bottom-left)

- Origin moved to bottom-left: preview matches standard machine/CAD coordinates
- (0,0) is at front-left corner; Y increases upward
- Y ruler flipped: 0 at bottom, max at top
- Row direction arrows updated: row 0 (▶ L→R) visually at bottom
- Path overlay corrected: snake path draws from bottom upward
- G-code coordinates unchanged (were already correct)

### v5 — Rulers, path direction overlay, SVG export

- X/Y axis rulers with mm scale; tick density adapts to zoom level
- Row direction arrows (▶/◀) in Y ruler showing snake-path travel direction per row
- Show Path toggle: overlays full snake path with arrowheads
- SVG download: physically accurate (`width="Nmm"`), circles at real mm coordinates

### v4 — Gap-based spacing model + live spacing display

- Gap input replaces manual spacing: user sets edge-to-edge clearance (default 1 mm)
- Spacing auto-computed: `diameter + gap`; shown live before Apply Grid
- G-code header now logs diameter, gap, and spacing separately

### v3 — Separate files + bead spacing/diameter split

- Refactored into `index.html`, `style.css`, `script.js`
- Bead spacing (center-to-center pitch) and bead diameter split into separate inputs
- Accurate circle sizing: `radiusPx = (diameter / spacing) × cellPx / 2`

### v2 — Two-phase UX + circles + color pickers + origin

- Two-phase workflow: setup → Apply Grid → design tools unlock
- Configurable bed size
- Beads rendered as circles (not squares)
- Live bead count stats
- Color pickers for black bead, white bead, space
- Origin X/Y inputs offset all G-code coordinates

### v1 — Initial version

- Grid canvas with pen and eraser tools
- Configurable bead size and dwell time
- Image import with luminance thresholding
- G-code generation with snake path and dual feeder control

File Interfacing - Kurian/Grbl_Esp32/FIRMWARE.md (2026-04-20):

# Pixel Art Machine — Firmware Documentation

Grbl_ESP32 firmware configured for a CoreXY bead-placement machine.
Based on [Grbl_ESP32 by Bart Dring](https://github.com/bdring/Grbl_Esp32).

---

## Table of Contents

1. [Overview](#1-overview)
2. [File Structure](#2-file-structure)
3. [Active Machine Configuration — Pixelart.h](#3-active-machine-configuration--pixelarth)
4. [Pin Map](#4-pin-map)
5. [CoreXY Kinematics — CoreXY.cpp](#5-corexy-kinematics--corexypp)
6. [Homing Sequence](#6-homing-sequence)
7. [Default Settings — Defaults.h](#7-default-settings--defaultsh)
8. [Spindle / Bead Feeder Status](#8-spindle--bead-feeder-status)
9. [Serial Communication](#9-serial-communication)
10. [Status Report Format](#10-status-report-format)
11. [Known Issues & Notes](#11-known-issues--notes)
12. [How to Flash](#12-how-to-flash)
13. [Runtime Settings ($$ Commands)](#13-runtime-settings--commands)

---

## 1. Overview

| Property | Value |
|---|---|
| Base firmware | Grbl_ESP32 (Grbl 1.3a) |
| Target hardware | ESP32 dev board |
| Machine type | CoreXY |
| Machine name | `PIXELART_COREXY_TEST` |
| Kinematics file | `Custom/CoreXY.cpp` |
| Active machine file | `src/Machines/Pixelart.h` |
| Baud rate | 115200 |
| Step generation | RMT peripheral (`USE_RMT_STEPS`) |
| Axes used | X, Y only (Z defined but unused) |
| Bluetooth | Enabled |

---

## 2. File Structure

```
Grbl_Esp32/
├── Grbl_Esp32.ino              — Entry point: calls grbl_init() and run_once()
├── data/
│   └── index.html.gz           — Web UI (served from ESP32 flash)
├── Custom/
│   └── CoreXY.cpp              — CoreXY inverse/forward kinematics + custom homing
└── src/
    ├── Machine.h               — Selects the active machine file (points to Pixelart.h)
    ├── MachineCommon.h         — SPI and timer constants, never changes
    ├── Config.h                — Compile-time system config (baud, N_AXIS, USE_RMT, etc.)
    ├── Defaults.h              — Default values for all $$ runtime settings
    ├── Machines/
    │   └── Pixelart.h          ← ACTIVE MACHINE CONFIG — edit this for hardware changes
    ├── Motors/                 — Motor driver classes (Standard, Trinamic, Servo, etc.)
    ├── Spindles/               — Spindle driver classes (PWM, Relay, BESC, Laser, etc.)
    └── WebUI/                  — WiFi/BT web interface
```

**The only files that normally need editing for this machine:**
- `src/Machines/Pixelart.h` — pin assignments, homing config, spindle selection
- `Custom/CoreXY.cpp` — kinematics (only if motion geometry changes)
- `src/Defaults.h` — default values for steps/mm, speeds, travel limits

---

## 3. Active Machine Configuration — Pixelart.h

**File:** `src/Machines/Pixelart.h`

This is the single file that defines the entire hardware mapping for the pixel art machine. It is selected in `src/Machine.h` with `#include "Machines/Pixelart.h"`.

```cpp
#define MACHINE_NAME "PIXELART_COREXY_TEST"
#define CUSTOM_CODE_FILENAME "../Custom/CoreXY.cpp"

// Motor step & direction pins
#define X_STEP_PIN              GPIO_NUM_12
#define X_DIRECTION_PIN         GPIO_NUM_26
#define Y_STEP_PIN              GPIO_NUM_14
#define Y_DIRECTION_PIN         GPIO_NUM_25

// Limit switch pins
#define X_LIMIT_PIN             GPIO_NUM_21
#define Y_LIMIT_PIN             GPIO_NUM_4

// Stepper enable (active LOW)
#define STEPPERS_DISABLE_PIN    GPIO_NUM_13

// Homing
#define DEFAULT_HOMING_ENABLE          1
#define DEFAULT_HOMING_CYCLE_1         bit(X_AXIS)   // cycle 1 = home X
#define DEFAULT_HOMING_CYCLE_2         bit(Y_AXIS)   // cycle 2 = home Y
#define DEFAULT_HOMING_DIR_MASK        (bit(X_AXIS) | bit(Y_AXIS))  // both home negative
#define DEFAULT_HOMING_DEBOUNCE_DELAY  250  // ms
#define DEFAULT_HOMING_PULLOFF         3.0  // mm

// Limits
#define DEFAULT_SOFT_LIMIT_ENABLE  0  // disabled
#define DEFAULT_HARD_LIMIT_ENABLE  1  // enabled

// Spindle — NOT YET DEFINED (bead feeders not wired)
// #define SPINDLE_TYPE          SpindleType::BESC
// #define SPINDLE_OUTPUT_PIN    GPIO_NUM_17
// #define SPINDLE_ENABLE_PIN    GPIO_NUM_22
```

---

## 4. Pin Map

| GPIO | Function | Direction | Notes |
|---|---|---|---|
| GPIO 12 | X_STEP | Output | Step pulse for motor A |
| GPIO 26 | X_DIRECTION | Output | Direction for motor A |
| GPIO 14 | Y_STEP | Output | Step pulse for motor B |
| GPIO 25 | Y_DIRECTION | Output | Direction for motor B |
| GPIO 21 | X_LIMIT | Input | X axis limit switch (homed to this) |
| GPIO 4  | Y_LIMIT | Input | Y axis limit switch (homed to this) |
| GPIO 13 | STEPPERS_DISABLE | Output | Active LOW — pull LOW to enable drivers |

**Limit switch logic:**
- `DEFAULT_INVERT_LIMIT_PINS = 1` (set in Defaults.h)
- Switches are treated as **normally closed (NC)** — pin reads HIGH when switch is open, LOW when triggered
- If using normally open (NO) switches, set `$5=0`

**Spindle / Feeder pins — NOT YET ASSIGNED:**
The following are commented out in Pixelart.h and must be defined before bead feeders will work:
```cpp
// #define SPINDLE_TYPE        SpindleType::BESC   (or PWM, Relay, etc.)
// #define SPINDLE_OUTPUT_PIN  GPIO_NUM_17
// #define SPINDLE_ENABLE_PIN  GPIO_NUM_22
```

---

## 5. CoreXY Kinematics — CoreXY.cpp

**File:** `Custom/CoreXY.cpp`

### Motor-to-Cartesian Mapping

In CoreXY, both physical motors drive both X and Y cartesian movement:

```
Motor A steps = X_cartesian + Y_cartesian
Motor B steps = X_cartesian - Y_cartesian
```

Inverse (motors → cartesian):
```
X_cartesian = 0.5 × (Motor_A + Motor_B)
Y_cartesian = 0.5 × (Motor_A - Motor_B)
```

This is implemented in `transform_cartesian_to_motors()` and `motors_to_cartesian()`.

**Consequence:** For pure X movement, both motors run at equal speed in the same direction. For pure Y movement, both motors run at equal speed in opposite directions. Any single motor failure will cause diagonal drift, not total failure.

### geometry_factor

Set to `1.0` (standard CoreXY). Not a midTbot variant.

### Homing Constraint

CoreXY **requires each axis to be homed in a separate cycle** — you cannot home X and Y simultaneously because the motor-to-cartesian transform means simultaneous X and Y moves require coordinated motor motion. The firmware enforces this:

```cpp
// CoreXY Multi axis homing cycles not allowed.
if (numberOfSetBits(homing_cycle[cycle]->get()) > 1) {
    // error!
}
```

This is why `Pixelart.h` defines:
```cpp
#define DEFAULT_HOMING_CYCLE_1  bit(X_AXIS)   // X homes first
#define DEFAULT_HOMING_CYCLE_2  bit(Y_AXIS)   // Y homes second
```

### Homing Motor Motion

When homing X axis: both motors move in the **same direction** (X_cart moves, Y_cart=0)
When homing Y axis: both motors move in **opposite directions** (X_cart=0, Y_cart moves)

After homing, the system position is set based on the homing direction mask and pull-off distance.

---

## 6. Homing Sequence

Full `$H` execution order:

```
1. Check cycles — error if any cycle has >1 axis (CoreXY limitation)
2. Cycle 1: Home X axis
   a. Both motors move in negative X direction (seek rate: 2000 mm/min)
   b. X limit switch (GPIO 21) triggers
   c. Motors stop, debounce 250ms
   d. Pull off 3mm
   e. Slow approach (feed rate: 200 mm/min)
   f. X limit triggers again → X position locked
3. Cycle 2: Home Y axis
   a. Both motors move in negative Y direction (motors go opposite ways)
   b. Y limit switch (GPIO 4) triggers
   c. Motors stop, debounce 250ms
   d. Pull off 3mm
   e. Slow approach
   f. Y limit triggers → Y position locked
4. Set cartesian position to (pulloff, pulloff) = (3.0, 3.0) mm
5. Sync GCode parser and planner positions
```

**ALARM:9** = `HomingFailApproach` — the axis travelled the full `max_travel × 1.1` distance without triggering the limit switch.

**Causes of ALARM:9 on Y:**
- Y limit switch (GPIO 4) not wired or not triggering
- Homing direction wrong — Y axis moving away from switch (`$23` value)
- Max travel too small — machine reaches travel limit before reaching switch (`$131`)
- Switch type mismatch — NC vs NO (`$5=1` means NC expected)

**Diagnostic:** Send `?` while manually pressing the Y limit switch. Look for `Pn:Y` in the response. If it doesn't appear, the switch is not registering.

---

## 7. Default Settings — Defaults.h

These are the **compiled-in defaults**. They are used when the ESP32 flash is cleared or `$RST=*` is sent. Runtime values can differ (shown by `$$`).

| Setting | Parameter | Value | Unit |
|---|---|---|---|
| `$0` | Step pulse time | 3 | µs |
| `$1` | Stepper idle lock time | 250 | ms |
| `$2` | Step invert mask | 0 | bitmask |
| `$3` | Direction invert mask | 0 | bitmask |
| `$4` | Invert step enable | 0 | boolean |
| `$5` | Invert limit pins | **1** | boolean (NC switches) |
| `$10` | Status report mask | 1 | bitmask |
| `$20` | Soft limits | 0 | disabled |
| `$21` | Hard limits | **1** | enabled |
| `$22` | Homing enable | **1** | enabled |
| `$23` | Homing dir mask | **3** (both axes negative) | bitmask |
| `$24` | Homing feed rate | 200 | mm/min |
| `$25` | Homing seek rate | 2000 | mm/min |
| `$26` | Homing debounce | 250 | ms |
| `$27` | Homing pull-off | **3.0** | mm |
| `$30` | Spindle max RPM | 1000 | RPM |
| `$31` | Spindle min RPM | 0 | RPM |
| `$100` | X steps/mm | 100.0 | steps/mm |
| `$101` | Y steps/mm | 100.0 | steps/mm |
| `$110` | X max rate | 1000 | mm/min |
| `$111` | Y max rate | 1000 | mm/min |
| `$120` | X acceleration | 200 | mm/s² |
| `$121` | Y acceleration | 200 | mm/s² |
| `$130` | X max travel | 300 | mm |
| `$131` | Y max travel | 300 | mm |

**Bold values are set or overridden in Pixelart.h** — the rest come from Defaults.h.

> Steps/mm (100.0) and max travel (300 mm) are generic defaults. These must be calibrated and updated via `$100`, `$101`, `$130`, `$131` for the actual machine hardware.

---

## 8. Spindle / Bead Feeder Status

**Current state: NOT IMPLEMENTED**

The spindle section in `Pixelart.h` is entirely commented out:

```cpp
// #define SPINDLE_TYPE            SpindleType::BESC
// #define SPINDLE_OUTPUT_PIN      GPIO_NUM_17
// #define SPINDLE_ENABLE_PIN      GPIO_NUM_22
```

Because no `SPINDLE_TYPE` is defined, the firmware defaults to `SpindleType::NONE` (from Defaults.h):

```cpp
#ifndef SPINDLE_TYPE
#    define SPINDLE_TYPE SpindleType::NONE
#endif
```

**What this means:**
- `M3 S100`, `M4 S100`, and `M5` commands are **accepted** by the GRBL parser and return `ok`
- **No GPIO pin is toggled** — nothing happens in hardware
- The bead feeders are not yet connected to any output

**What needs to be done to enable feeders:**

The browser app uses:
- `M3 S100` → Black bead feeder ON
- `M4 S100` → White bead feeder ON
- `M5`      → All feeders OFF

To wire this up in the firmware, uncomment and configure in `Pixelart.h`:

```cpp
// Option 1: PWM spindle (variable speed motor/servo)
#define SPINDLE_TYPE        SpindleType::PWM
#define SPINDLE_OUTPUT_PIN  GPIO_NUM_17   // PWM signal for feeder A (black, M3)
#define SPINDLE_ENABLE_PIN  GPIO_NUM_22   // enable pin

// Option 2: Relay spindle (on/off only)
#define SPINDLE_TYPE        SpindleType::RELAY
#define SPINDLE_OUTPUT_PIN  GPIO_NUM_17   // relay trigger for feeder A
```

For two separate feeders (black and white), a custom spindle class or the UserOutput pins will be needed, since standard GRBL spindle only drives one output direction and uses M3/M4 for CW/CCW. The `UserOutput` module (`src/UserOutput.cpp`) provides `M62`/`M63` for additional digital outputs and may be used for a second feeder.

---

## 9. Serial Communication

| Parameter | Value |
|---|---|
| Baud rate | 115200 |
| Defined in | `src/Config.h` → `#define BAUD_RATE 115200` |
| Protocol | GRBL 1.1 (text, newline-terminated) |
| Bluetooth | Also available (enabled in Config.h) |

On boot, the firmware sends:
```
Grbl 1.3a ['$' for help]
```

If previously in ALARM state it may also send:
```
[MSG:'$H'|'$X' to unlock]
```

---

## 10. Status Report Format

The firmware sends `MPos` (machine position) **not** `WPos` (work position), along with `WCO` (work coordinate offset):

```
<Idle|MPos:0.000,0.000,0.000|FS:0,0|WCO:0.000,0.000,0.000>
<Run|MPos:10.500,25.000,0.000|FS:3000,0>
<Alarm:9|MPos:0.000,0.000,0.000|FS:0,0|WCO:0.000,0.000,0.000>
```

**Work position can be calculated as:**
```
WPos = MPos + WCO
```

**Important for the browser app:** The app currently parses `WPos:` from the status report. Since the firmware sends `MPos:`, the position display will not update. The app needs to be updated to parse `MPos:` (or `WPos:` if WCO offset is applied).

### Status field meanings

| Field | Meaning |
|---|---|
| `Idle` | No motion, ready for commands |
| `Run` | Executing motion |
| `Hold:0` | Feed hold in progress (decelerating) |
| `Hold:1` | Feed hold complete (stopped) |
| `Jog` | Executing a jog move |
| `Alarm:N` | Alarm state — machine locked. Send `$X` to clear |
| `Home` | Homing cycle in progress |
| `MPos:x,y,z` | Machine position in mm |
| `WCO:x,y,z` | Work coordinate offset |
| `FS:feed,spindle` | Current feed rate (mm/min) and spindle speed |
| `Pn:XY` | Active input pins (X = X limit active, Y = Y limit active) |

---

## 11. Known Issues & Notes

### Issue 1: Y axis homing fails (ALARM:9)

**Symptom:** X homes correctly, Y does not move or triggers ALARM:9.

**Diagnosis steps:**
1. Send `$$` — check `$22` (homing enable), `$23` (homing direction), `$131` (Y max travel)
2. Send `?` while manually pressing Y limit switch — check for `Pn:Y` in response
3. If `Pn:Y` does not appear: switch wiring or GPIO 4 issue
4. If `Pn:Y` appears but homing still fails: direction or travel distance issue

**Quick fix attempt:** `$22=3` then `$H` (ensures both axes are in homing cycle)

### Issue 2: Position display not updating in browser app

**Cause:** Firmware sends `MPos:` but app parses `WPos:`. The regex `/WPos:([-\d.]+),([-\d.]+)/` will never match.

**Fix needed in script.js:** Update `parseGrblStatus()` to also match `MPos:`:
```javascript
const pos = s.match(/[WM]Pos:([-\d.]+),([-\d.]+)/);
```

### Issue 3: Bead feeders not connected

**Cause:** `SPINDLE_TYPE` is commented out in Pixelart.h. M3/M4/M5 return `ok` but do nothing.

**Fix:** Define spindle type and output pin in Pixelart.h and reflash.

### Issue 4: Garbled bytes on initial connect

**Cause:** ESP32 UART outputs garbage during boot before settling at 115200. Normal behaviour.

**Fix:** None needed — ignore the first line of data on connect.

### Issue 5: Steps/mm not calibrated

**Default value:** 100 steps/mm for both X and Y.

**Action required:** Physically measure actual movement (send `G0 X100`, measure real distance) and update with `$100=<correct_value>` and `$101=<correct_value>`.

---

## 12. How to Flash

1. Install Arduino IDE with ESP32 board support
2. Open `Grbl_Esp32/Grbl_Esp32.ino`
3. Ensure `src/Machine.h` includes `Machines/Pixelart.h` (already set)
4. Select board: **ESP32 Dev Module** (or matching board)
5. Select correct COM port
6. Click Upload
7. After flash, open Serial Monitor at 115200 baud
8. Should see: `Grbl 1.3a ['$' for help]`

**After first flash or after `$RST=*`:** All settings revert to the compiled-in defaults from `Defaults.h` and `Pixelart.h`. Re-apply any calibrated values (`$100`, `$101`, `$130`, `$131`, etc.).

---

## 13. Runtime Settings ($$ Commands)

Send `$$` in the serial terminal to see all current runtime settings. Key settings to verify and calibrate:

```
$5=1        Limit pins inverted (1 = NC switches) ← set in Defaults.h
$21=1       Hard limits enabled
$22=1       Homing enabled
$23=3       Homing direction (3 = both X and Y home negative)
$24=200     Homing feed rate (mm/min) — slow approach
$25=2000    Homing seek rate (mm/min) — fast initial move
$26=250     Homing debounce (ms)
$27=3       Homing pull-off (mm) ← set in Pixelart.h

$100=???    X steps/mm — MUST BE CALIBRATED
$101=???    Y steps/mm — MUST BE CALIBRATED
$110=1000   X max rate (mm/min)
$111=1000   Y max rate (mm/min)
$120=200    X acceleration (mm/s²)
$121=200    Y acceleration (mm/s²)
$130=300    X max travel (mm) — update to actual bed size
$131=300    Y max travel (mm) — update to actual bed size
```

**To set a value:** `$100=142.857` (example for a 1.8° stepper, 16 microsteps, GT2 belt, 20-tooth pulley)

**Formula for steps/mm:**
```
steps/mm = (motor_steps_per_rev × microsteps) / (pulley_teeth × belt_pitch_mm)

Example: 200 steps/rev × 16 microsteps / (20 teeth × 2mm pitch) = 80 steps/mm
```

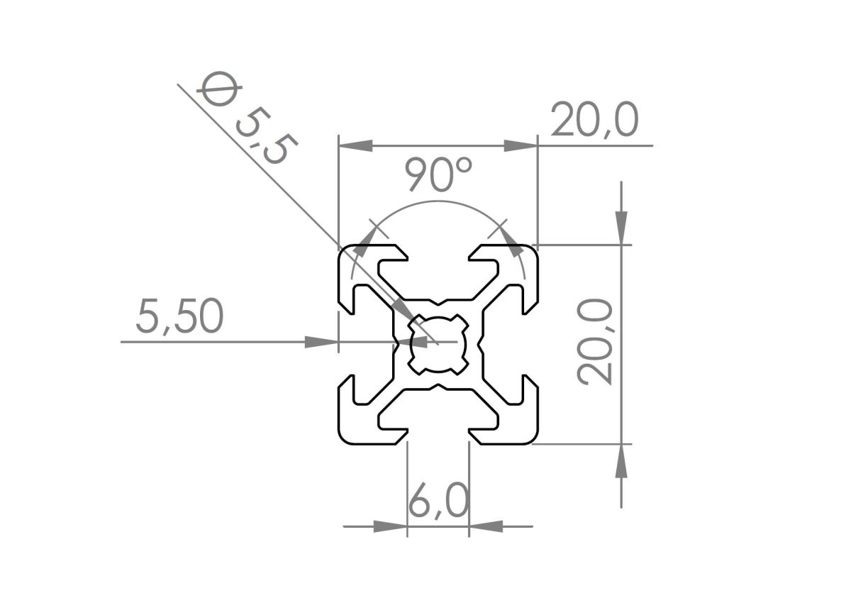
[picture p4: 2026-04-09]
Core-XY Movement - Nadec/initial files/technical-drawing-silver-aluminium-v-slot-profile-2020-20x20m-5815-en-G.jpg

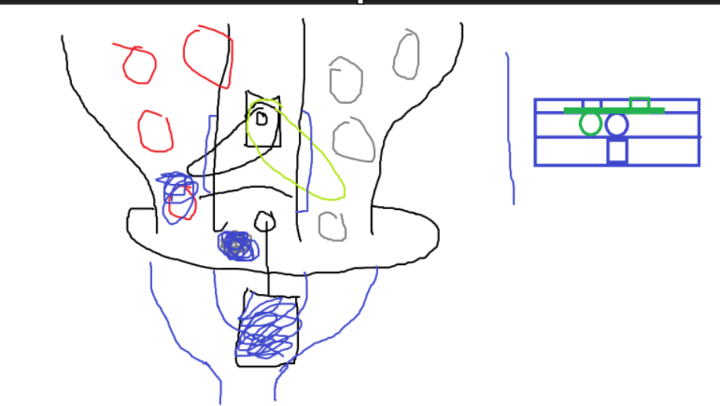
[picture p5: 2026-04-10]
Documentation/SKETCH-1.png

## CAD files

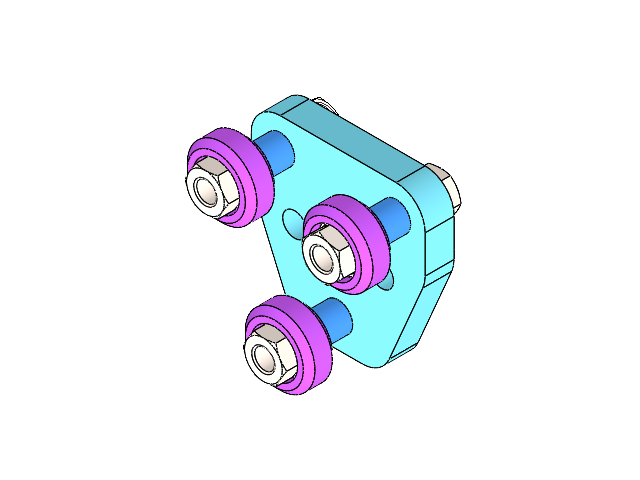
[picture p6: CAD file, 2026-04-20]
Core-XY Movement - Nadec/Solidworks Files/roller holder.SLDASM
Part55^roller holder
B18.2.3.2M - Formed hex screw, M8 x 1.25 x 30 --30WC x 3
Part56^roller holder x 3
Part54^roller for extrusion x 3
AFBMA 12.2 - 0.3750 - 0.6250 - 0.1562 - 16,SI,NC,16 x 3
B18.2.4.1M - Hex nut, Style 1, M8 x 1.25 --D-N x 3

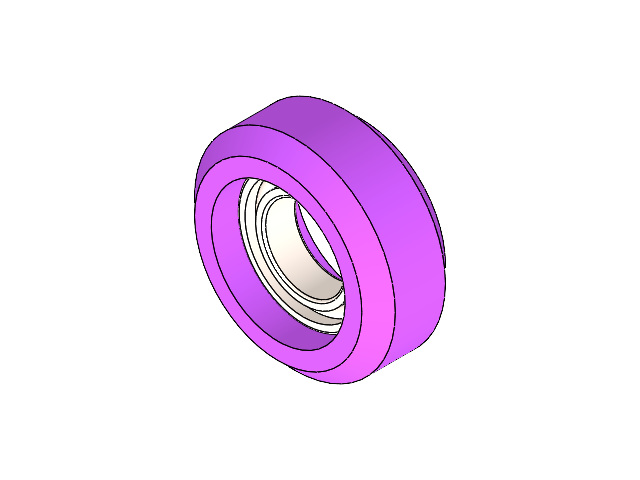
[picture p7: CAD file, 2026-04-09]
Core-XY Movement - Nadec/initial files/Backup (2) of roller for extrusion.SLDASM
Part54^roller for extrusion
AFBMA 12.2 - 0.3750 - 0.6250 - 0.1562 - 16,SI,NC,16

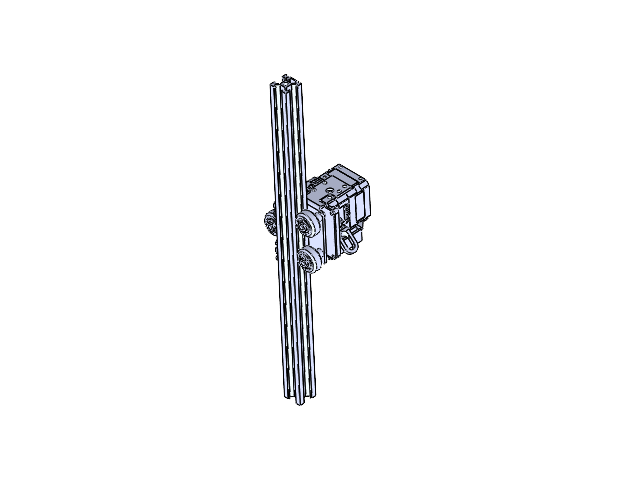
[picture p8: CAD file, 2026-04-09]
Core-XY Movement - Nadec/initial files/s1pro.SLDASM
Spacers for rollers x 3
Rollers x 3
M5X30 Pan Head Screw x 3
625pillow x 6
M5 Self-locking nut x 3
Mounting-0

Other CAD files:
Core-XY Movement - Nadec/initial files/Main Assembly.SLDASM
Core-XY Movement - Nadec/Solidworks Files/roller for extrusion.SLDASM
Core-XY Movement - Nadec/v2 packed and went/y_axis.SLDASM
Core-XY Movement - Nadec/v2 packed and went/GT2_BELT_PULLEY_TEMPLATE_v2 v5.SLDASM
Core-XY Movement - Nadec/Solidworks Files/Backup (1) of roller holder.SLDASM
Core-XY Movement - Nadec/v2 packed and went/Backup (1) of gantry.SLDASM
Core-XY Movement - Nadec/initial files/Backup (1) of roller holder.SLDASM
Core-XY Movement - Nadec/initial files/Backup (1) of !!Sprite Extruder v31.SLDASM
Core-XY Movement - Nadec/v2.0 final i guess/Backup (1) of GT2_BELT_PULLEY_TEMPLATE_v2 v5.SLDASM
Core-XY Movement - Nadec/initial files/roller holder.SLDASM
Core-XY Movement - Nadec/initial files/roller for extrusion.SLDASM
Core-XY Movement - Nadec/v2 packed and went/Backup (1) of y_axis.SLDASM
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

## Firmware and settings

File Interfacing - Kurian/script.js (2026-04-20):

// ── DOM refs ──────────────────────────────────────────────────
const canvas         = document.getElementById('grid-canvas');
const ctx            = canvas.getContext('2d');
const placeholder    = document.getElementById('placeholder');
const diameterInput  = document.getElementById('bead-diameter');
const gapInput       = document.getElementById('bead-gap');
const spacingValEl   = document.getElementById('spacing-val');
const bedWInput      = document.getElementById('bed-w');
const bedHInput      = document.getElementById('bed-h');
const dwellInput        = document.getElementById('dwell-time');
const originXInput      = document.getElementById('origin-x');
const originYInput      = document.getElementById('origin-y');
const blackBeadSideInput = document.getElementById('black-bead-side');
const whiteBeadSideInput = document.getElementById('white-bead-side');
const moveSpeedInput     = document.getElementById('move-speed');

// Servo S-values (calibrated)
const S_LEFT  = 120;
const S_REST  = 79;
const S_RIGHT = 40;
const gridInfoEl     = document.getElementById('grid-info');
const warningEl      = document.getElementById('warning');
const fileInput      = document.getElementById('file-input');

// ── Constants ─────────────────────────────────────────────────
const RULER_PX = 44;   // ruler strip thickness in pixels

// ── State ─────────────────────────────────────────────────────
let beadSpacingMm  = 7;   // center-to-center pitch = diameter + gap
let beadDiameterMm = 6;   // physical bead diameter (drives circle size)
let beadGapMm      = 1;   // edge-to-edge clearance between beads
let bedW = 400, bedH = 400;
let cols = 0, rows = 0, cellPx = 0;
let radiusPx = 0;
let grid = [];
let blackCount = 0;
let gridReady = false;
let isDrawing = false;
let activeTool = 'pen';
let lastPainted = null;
let showPath = false;

let colorBlack = '#1a1a1a';
let colorWhite = '#f0f0f0';
let colorSpace  = '#999999';

// ── Live spacing preview ──────────────────────────────────────
function updateSpacingDisplay() {
  const diam    = parseFloat(diameterInput.value) || 0;
  const gap     = parseFloat(gapInput.value)      || 0;
  const spacing = diam + gap;
  spacingValEl.textContent = spacing % 1 === 0 ? spacing.toFixed(1) : spacing.toFixed(2);
}

diameterInput.addEventListener('input', updateSpacingDisplay);
gapInput.addEventListener('input',      updateSpacingDisplay);

// ── Enable / disable design tools ────────────────────────────
function setToolsEnabled(on) {
  document.querySelectorAll('.tool-btn, #btn-import, #btn-clear, #btn-svg').forEach(el => {
    el.disabled = !on;
  });
  document.getElementById('btn-gcode').disabled = !on;
}

// ── Stats display ─────────────────────────────────────────────
function updateStats() {
  const total = cols * rows;
  const white = total - blackCount;
  gridInfoEl.innerHTML =
    `Grid: <strong style="color:#e0e0e0">${cols} &times; ${rows}</strong><br>` +
    `Total&nbsp;&nbsp;: ${total.toLocaleString()}<br>` +
    `&#9679; Black: <strong style="color:#e0e0e0">${blackCount.toLocaleString()}</strong><br>` +
    `&#9675; White: ${white.toLocaleString()}`;
  warningEl.style.display = total > 40000 ? 'block' : 'none';
}

// ── Apply Grid ────────────────────────────────────────────────
document.getElementById('btn-apply').addEventListener('click', () => {
  const newBedW    = parseFloat(bedWInput.value)     || 400;
  const newBedH    = parseFloat(bedHInput.value)     || 400;
  const newDiam    = parseFloat(diameterInput.value) || 6;
  const newGap     = parseFloat(gapInput.value)      || 1;
  const newSpacing = newDiam + newGap;

  if (newBedW <= 0 || newBedH <= 0 || newDiam <= 0 || newGap <= 0) {
    alert('All values must be positive numbers.');
    return;
  }
  const newCols = Math.floor(newBedW / newSpacing);
  const newRows = Math.floor(newBedH / newSpacing);
  if (newCols < 1 || newRows < 1) {
    alert('Bead spacing is larger than the bed — no beads fit.');
    return;
  }
  if (gridReady && blackCount > 0) {
    if (!confirm('Applying a new grid will clear your current design. Continue?')) return;
  }

  bedW           = newBedW;
  bedH           = newBedH;
  beadDiameterMm = newDiam;
  beadGapMm      = newGap;
  beadSpacingMm  = newSpacing;
  cols           = newCols;
  rows           = newRows;

  cellPx   = Math.max(5, Math.min(40, Math.floor(680 / cols)));
  radiusPx = (beadDiameterMm / beadSpacingMm) * cellPx * 0.5;

  // Canvas size includes ruler margins on left and top
  canvas.width  = cols * cellPx + RULER_PX;
  canvas.height = rows * cellPx + RULER_PX;

  grid = Array.from({ length: rows }, () => new Uint8Array(cols));
  blackCount = 0;

  placeholder.style.display = 'none';
  canvas.style.display = 'block';
  document.getElementById('stats-section').style.display = 'block';

  gridReady = true;
  setToolsEnabled(true);
  updateStats();
  render();
  updateTimeDisplay();
});

// ── Ruler label step ──────────────────────────────────────────
// Returns how many beads between each labelled tick (ensures ≥45px spacing)
function rulerLabelStep() {
  const minPx     = 45;
  const perLabel  = Math.ceil(minPx / cellPx);
  const nice      = [1, 2, 5, 10, 20, 50, 100, 200, 500];
  return nice.find(s => s >= perLabel) || perLabel;
}
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

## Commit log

2026-04-09 first draft SolidWorks
    [!!Sprite Extruder v31.SLDASM, !01 MAIN ASM Ender_3_ASM Roller X-Axis v1.SLDASM, !CR-Touch-Dummy v15-1.SLDPRT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]
2026-04-09 readme: add dependencies section and move 3D model preview above overview
    Added GRBL, Grbl_ESP32, and NeoPI_Wireless with explanations for each.
    Moved 3D model Sketchfab link to top of README for immediate visibility.
2026-04-10 Add pixel art bead placer web interface
    Single-file HTML/CSS/JS app that lets the user draw a B&W pixel grid
    and export grbl_esp32-compatible GCode (M3/M4/M5 + G4 dwell, snake path).
2026-04-20 nadec new update
    [3684N13_Corrosion-Resistant Aluminum Gt Timing Belt Pulley.SLDPRT, 3693N16_High-Strength Gt Timing Belt Idler Pulley.SLDPRT, 4481N79_Steel Ball Bearing.SLDPRT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]
2026-04-20 new servo positions added
